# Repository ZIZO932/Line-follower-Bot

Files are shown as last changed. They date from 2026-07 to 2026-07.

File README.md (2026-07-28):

# Line Follower Bot

so this is my line follower robot, built it for competition and it actually won first place at TechnoXian. because of that im now representing Egypt at the world competition in Thailand which is insane to me

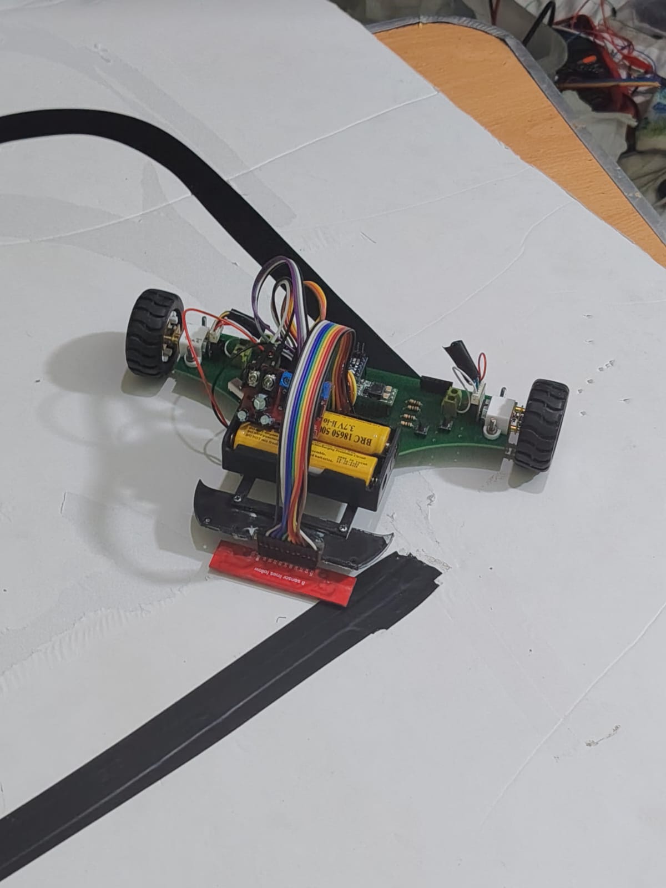
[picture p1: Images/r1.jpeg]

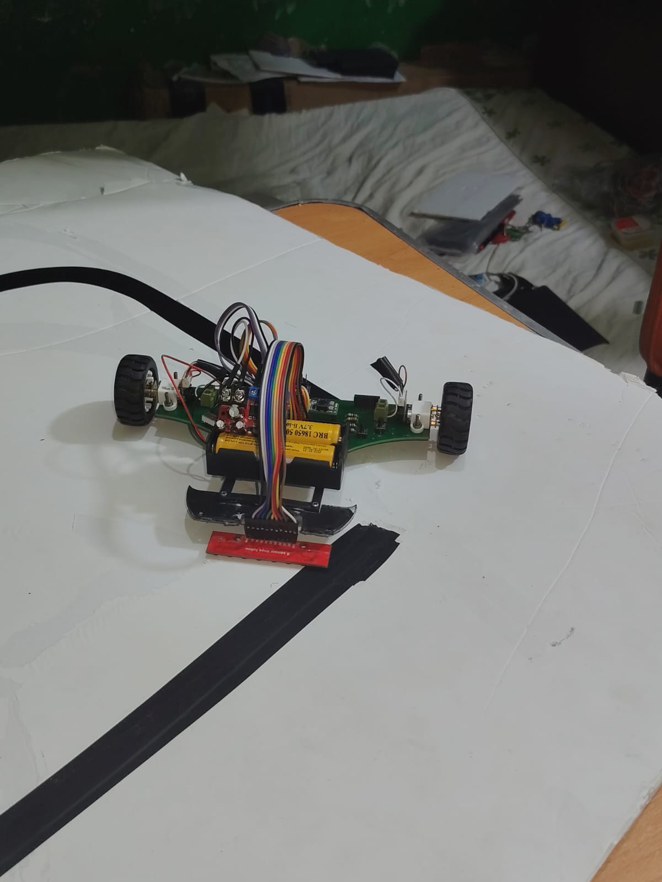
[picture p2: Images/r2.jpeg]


## what it is

a robot that follows a line using a sensor array under it and PID control to stay centered on the line. it can handle straights and sharp turns without losing the line. also has bluetooth so i can change the PID values live instead of reuploading code every single time i want to test something, which saved me so much time

## why i built it

wanted to actually understand PID instead of just copy pasting code from somewhere. looked at a bunch of existing line followers first, found one that used an Arduino Pro Mini with sensor calibration and liked that idea so i built my own version around it from scratch

## what's on it

- Arduino Pro Mini as the brain
- DRV8835 motor driver for the two motors
- QTR-8RC 8 channel line sensor array
- HC-05 bluetooth module for tuning
- 7.4V battery + voltage regulator to step it down to 5V
- power switch and some buttons

final PID values ended up being Kp=0.02, Ki=0, Kd=0.6 after a LOT of testing

## how i built it

started with research, watched tutorials on PID and read up on other line followers. then did the schematic, arduino + motor driver + sensor array + bluetooth + power stuff all wired together. had a bunch of errors at first, went through it connection by connection until it was clean

after that moved to PCB. had footprint issues, fixed those, then laid everything out and routed it. checked it like 3 times for unconnected nets and bad spacing before i was happy with it. added mounting holes so it screws into the body properly

did the 3D model around the PCB, made a spot for the sensor to sit low and aligned with the ground, and a little support to hold the battery so it doesnt move around while its driving

before the PCB even came in i breadboarded everything to test it. checked the arduino uploads fine, HC05 connects, both motors spin both directions on the driver, all 8 sensor channels give readings, regulator puts out a clean 5V. found some wiring mistakes doing this which was good bc caught them early

once the PCB arrived i soldered everything on, checked it over for bridges and bad orientation, used a multimeter to check power/ground before turning it on for the first time. then flashed the first test code to make sure everything talked to each other

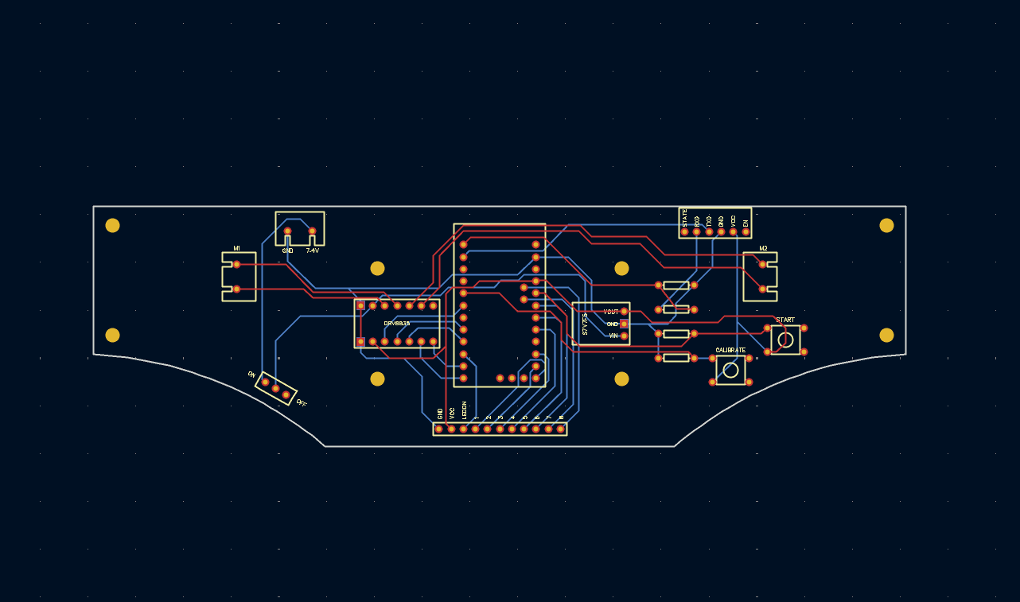
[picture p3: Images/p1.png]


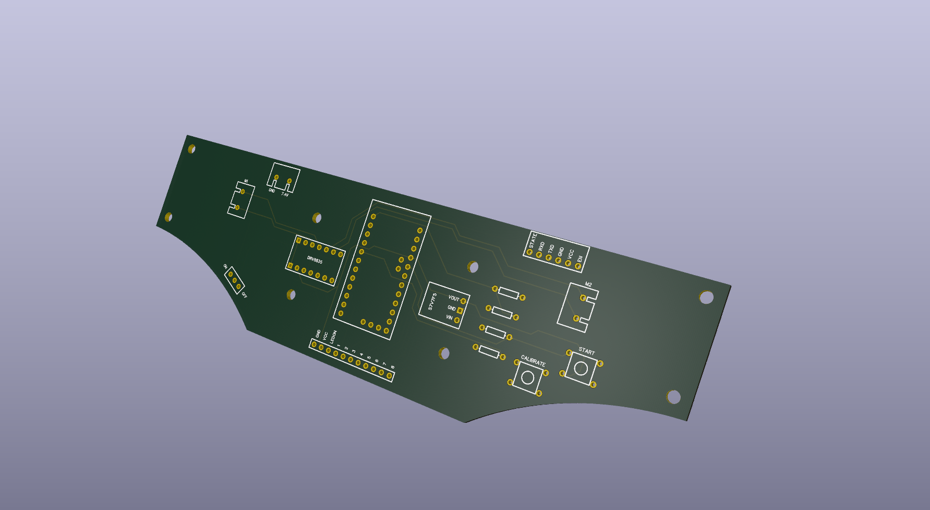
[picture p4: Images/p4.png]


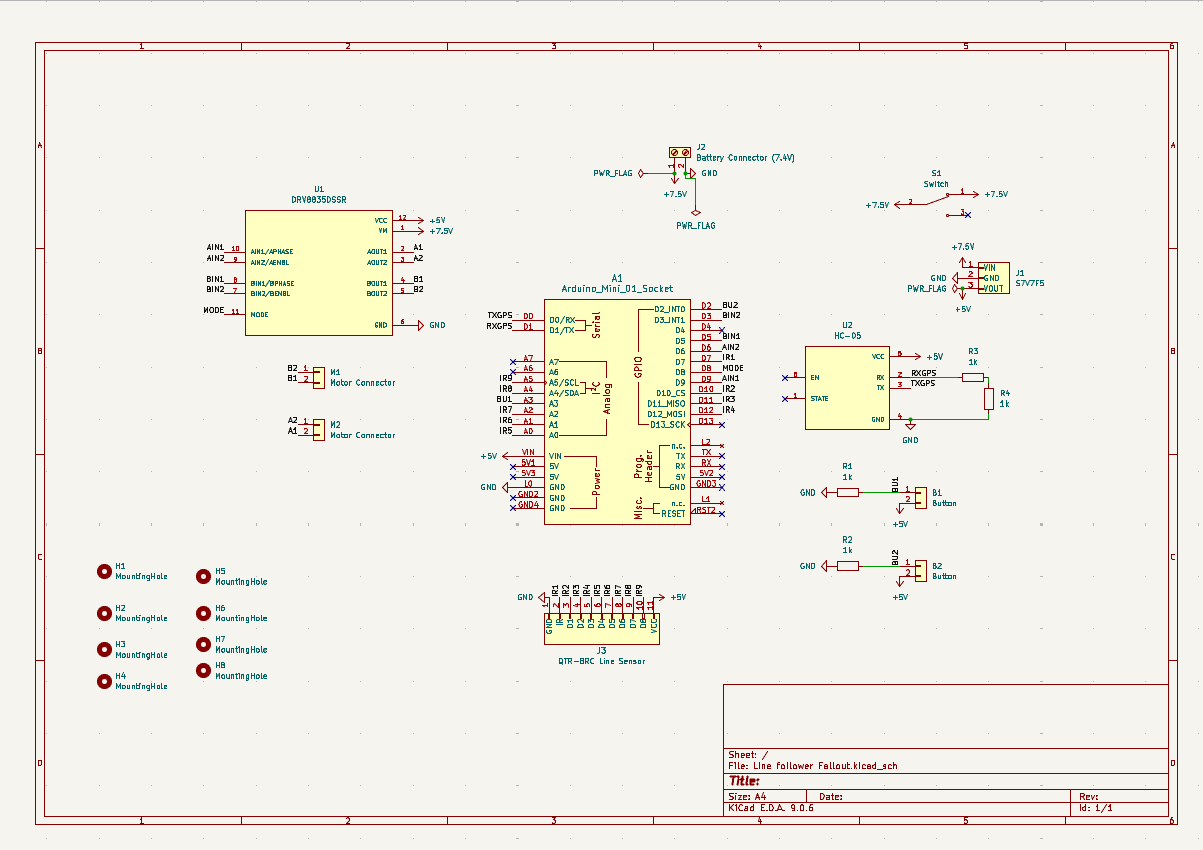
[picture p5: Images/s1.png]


## 3D model stuff

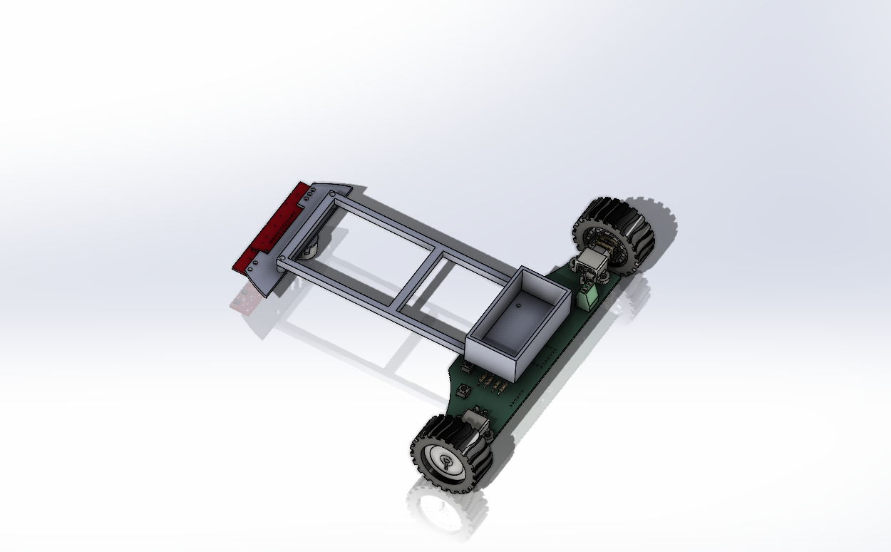
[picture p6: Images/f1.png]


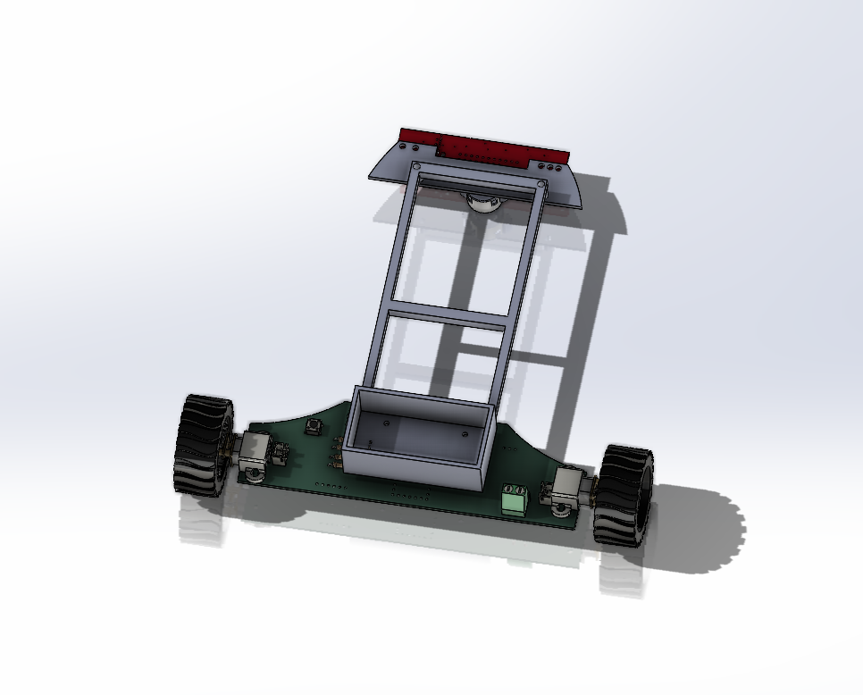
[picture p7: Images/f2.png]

## zine

made a zine for this project too, its in the repo

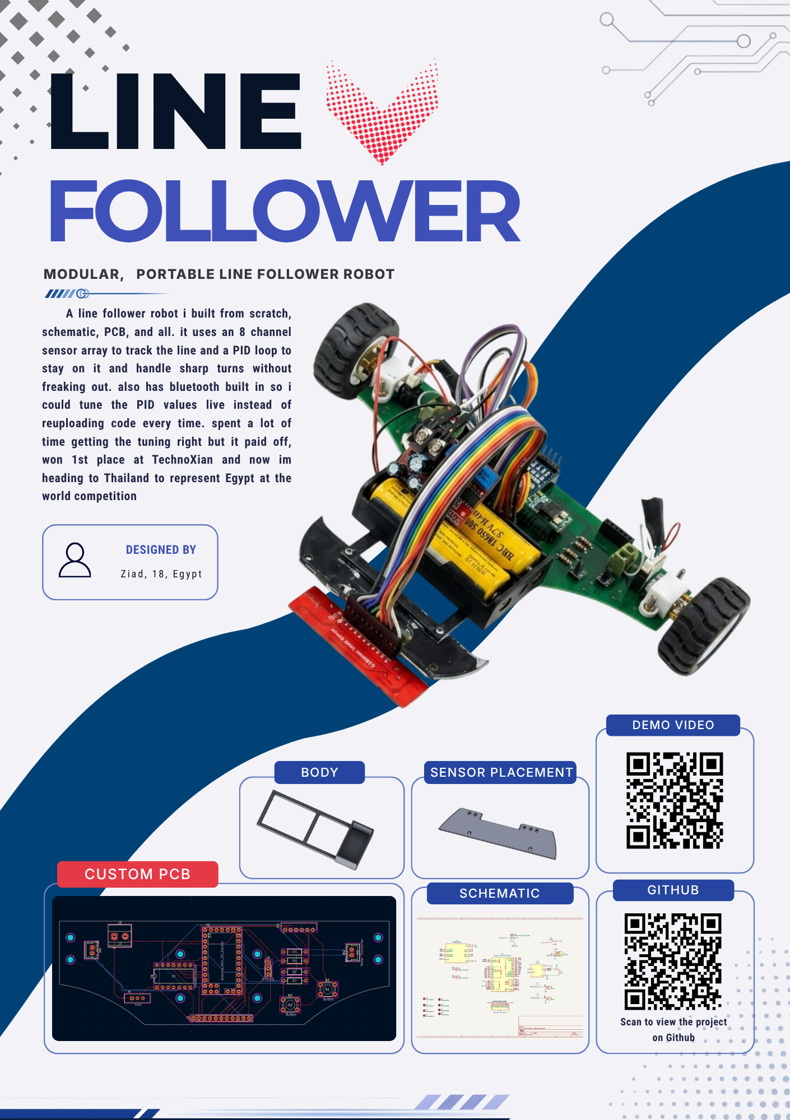
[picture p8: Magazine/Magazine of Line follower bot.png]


##BOM
|Component |Store |Qty|Unit Price (EGP)|Total (EGP) |Total (USD approx)|Link |
|---|---|---|---|---|---|---|
|Arduino Pro Mini 328 5V/16MHz |RAM Electronics |1  |250 |250 |4.98 |https://www.ram-e-shop.com/shop/arduino-mini-pro-arduino-pro-mini-328-5v-16mhz-7180 |
|DRV8835 Dual Motor Driver |Makers Electronics |1  |180 |180 |3.59 |https://makerselectronics.com/product/drv8833-2-channel-dc-motor-driver/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|
|QTR-8RC 8 Channel Line Sensor Array |Micro Ohm Electronics|1  |135 |135 |2.69 |https://microohm-eg.com/qtr-8rc-8-channel-line-tracker-reflectance-sensor-array/ |
|HC-05 Bluetooth Module (6 pin) |RAM Electronics |1  |200 |200 |3.98 |https://www.ram-e-shop.com/shop/kit-bluetooth-hc05-normal-hc-05-bluetooth-module-normal-6674 |
|7.4V Li-ion Battery Pack 2S-1P 1000mAh w/ BMS + JST|Makers Electronics |1  |210 |210 |4.18 |https://makerselectronics.com/product/rechargeable-li-ion-battery-pack-7-4v-2s-1pbms-1000mah-18650-with-jst-cable/ |
|L7805CV Voltage Regulator 5V/1A TO-220 |Micro Ohm Electronics|1  |6 |6 |0.12 |https://microohm-eg.com/product/7805-regulator-ic/ |
|DPDT Slide Power Switch (ON/ON 6 pin) |Micro Ohm Electronics|1  |10 |10 |0.2 |https://microohm-eg.com/on-on-switch-6-pin-pcb-mounted-22mm-dpdt-slide-switch/ |
|Tactile Push Button 12x12x12mm |Micro Ohm Electronics|1  |3.5 |3.5 |0.07 |https://microohm-eg.com/press-12x12x12mm-push-button-switch-4-pin/ |
|TOTAL | | | |994.50 (incl. DRV8835 estimate)|19.81 | |
## Demo videoo 

recorded a demo video that shows it can handle a small map in the s shape: https://youtu.be/TAyl4BceC5A

## results

first place at TechnoXian. now heading to the world competition in Thailand to represent Egypt

## made by

Ziad u can call me Zizo too if u want

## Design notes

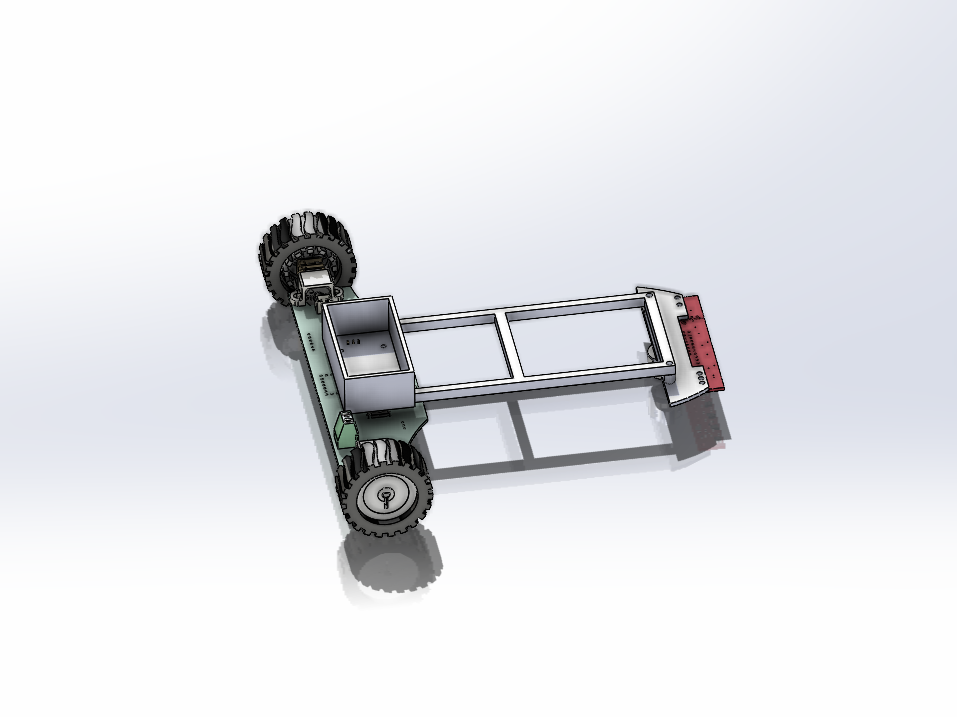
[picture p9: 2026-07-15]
Images/f3.png

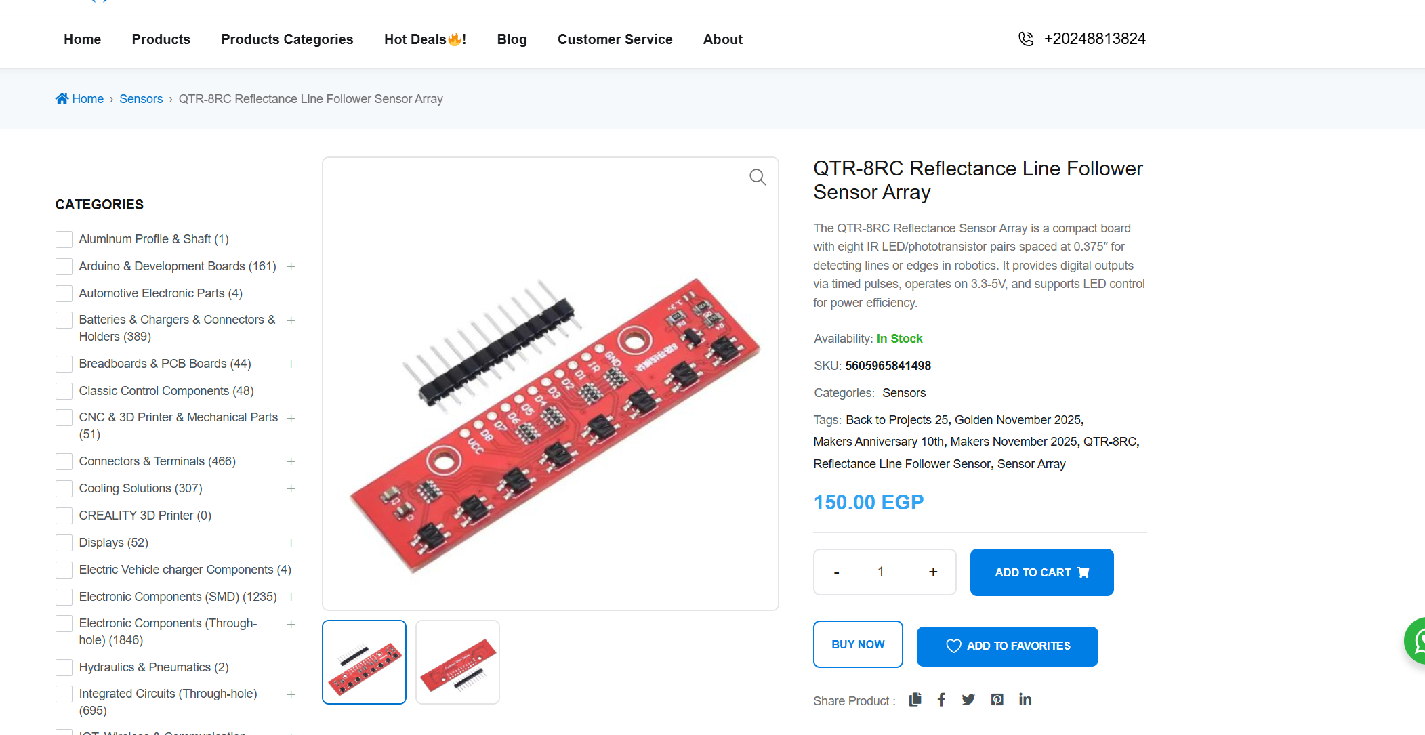
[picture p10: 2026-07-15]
Images/qtr.png

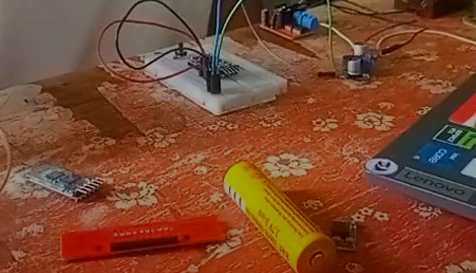
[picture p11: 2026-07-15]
Images/Screenshot 2026-07-15 085233 - Copy.png

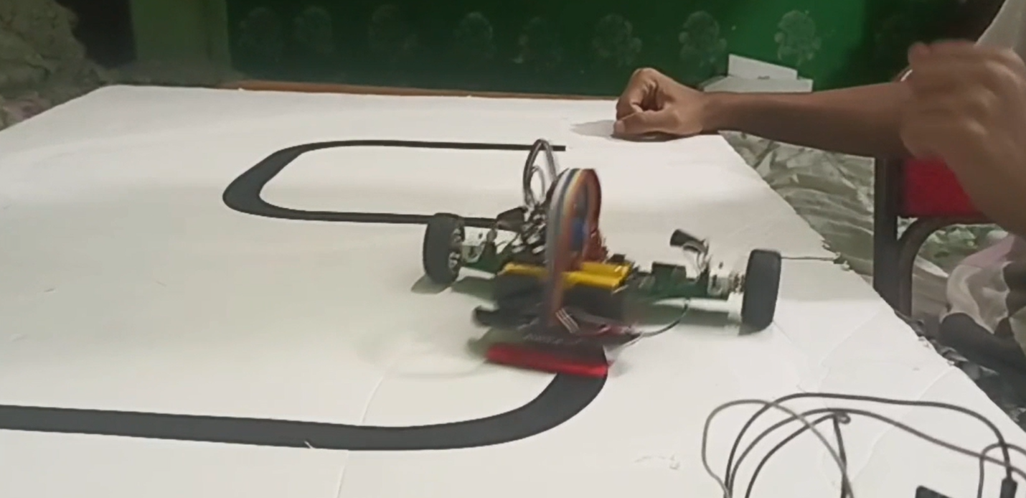
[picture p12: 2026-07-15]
Images/Screenshot 2026-07-15 090606 - Copy.png

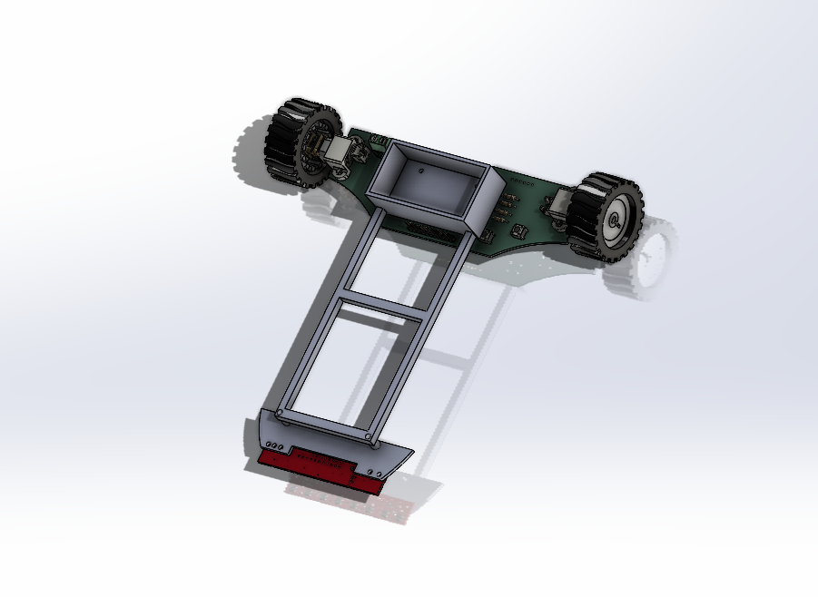
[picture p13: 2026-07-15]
Images/f5.png

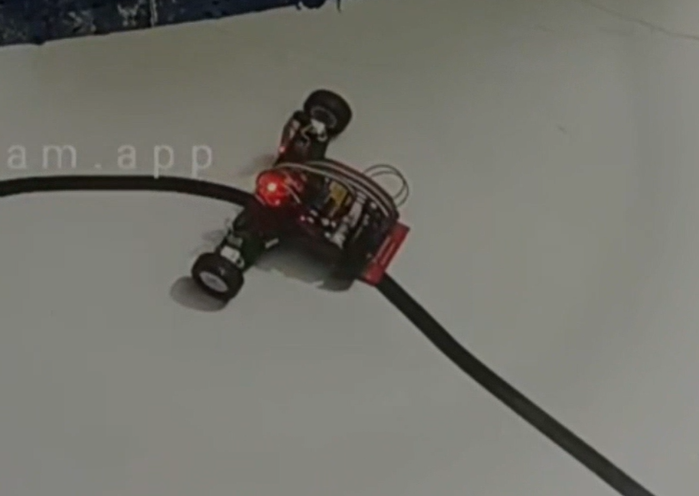
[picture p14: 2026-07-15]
Images/Screenshot 2026-07-15 090655 - Copy.png

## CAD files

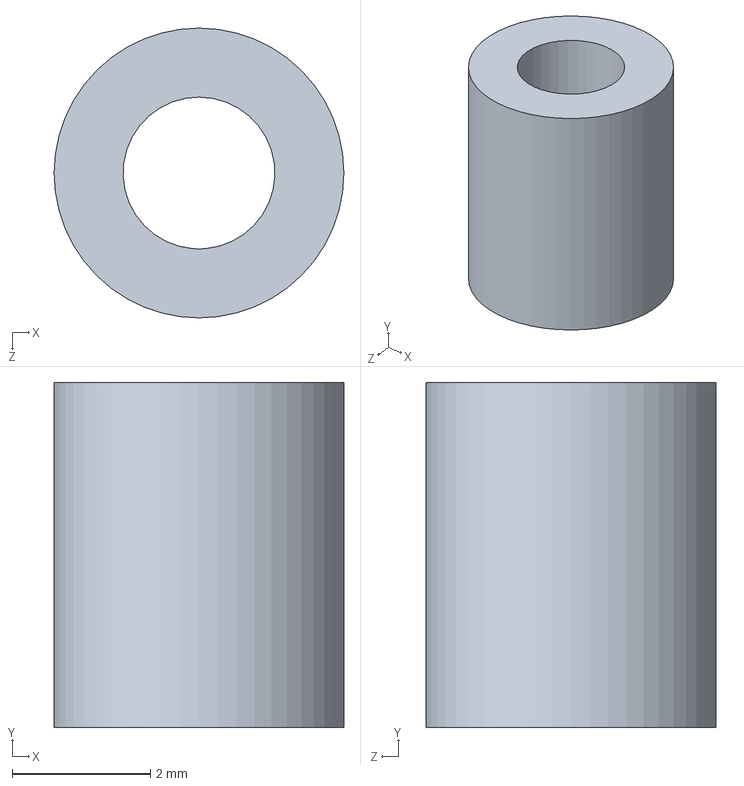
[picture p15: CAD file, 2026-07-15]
3D model source/Element1.SLDPRT
4.20 x 5.00 x 4.20 mm

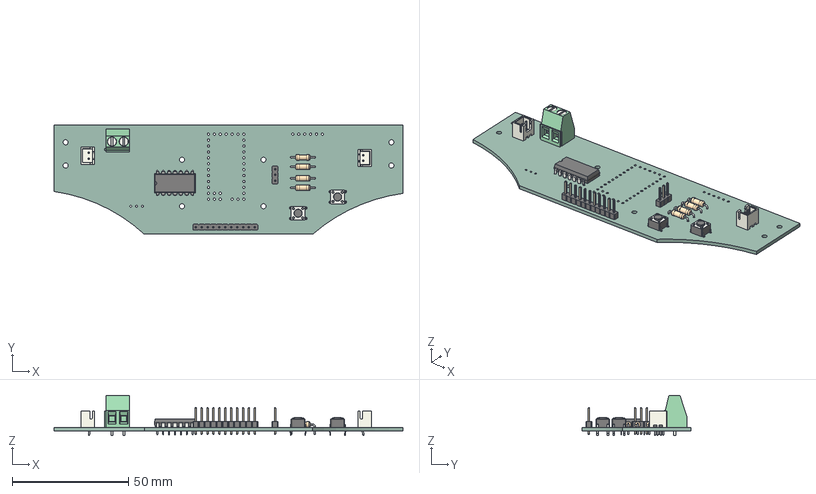
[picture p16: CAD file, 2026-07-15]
CAD/Line follower Fallout.step
150.0 x 47.0 x 17.3 mm
R_Axial_DIN0207_L6.3mm_D2.5mm_P10.16mm_Horizontal x 4
JST_XH_B2B-XH-A_1x02_P2.50mm_Vertical x 2
DIP-14_W10.16mm
TerminalBlock_Phoenix_MKDS-1,5-2-5.08_1x02_P5.08mm_Horizontal
PinHeader_1x03_P2.54mm_Vertical
SW_PUSH_6mm_H4.3mm x 2
PinHeader_1x11_P2.54mm_Vertical
Line follower Fallout_PCB

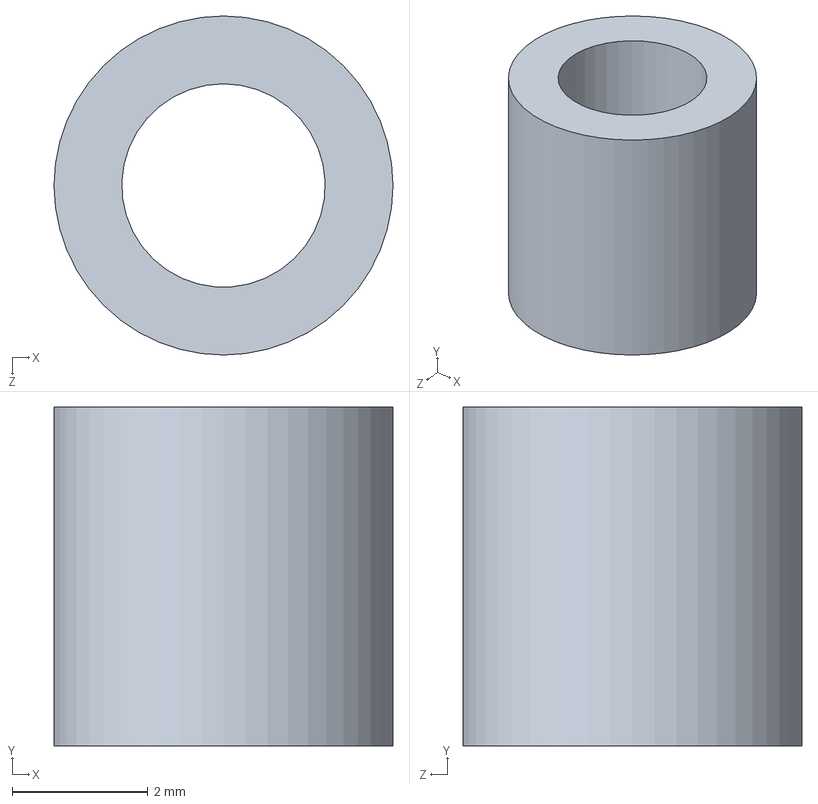
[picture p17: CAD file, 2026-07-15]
3D model source/Element2.SLDPRT
5.00 x 5.00 x 5.00 mm

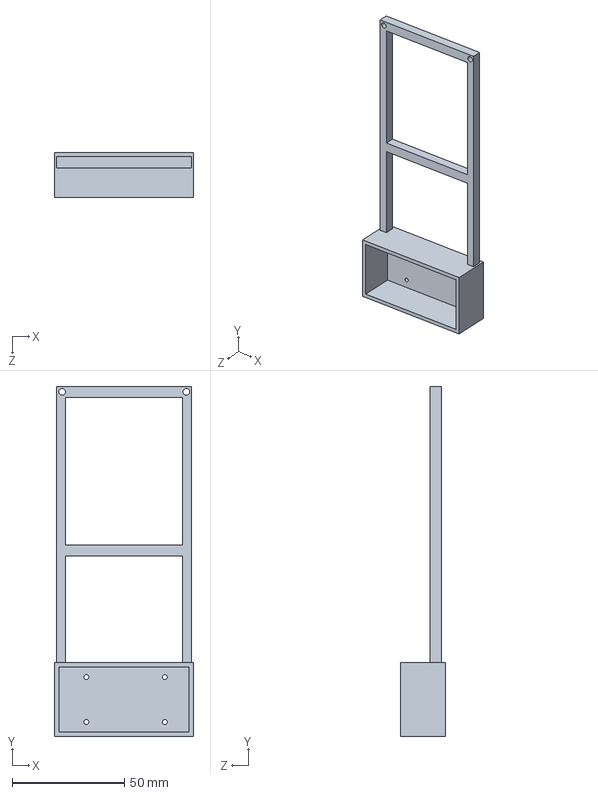
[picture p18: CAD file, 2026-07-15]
3D model source/battery support.SLDPRT
62.0 x 156.0 x 20.0 mm

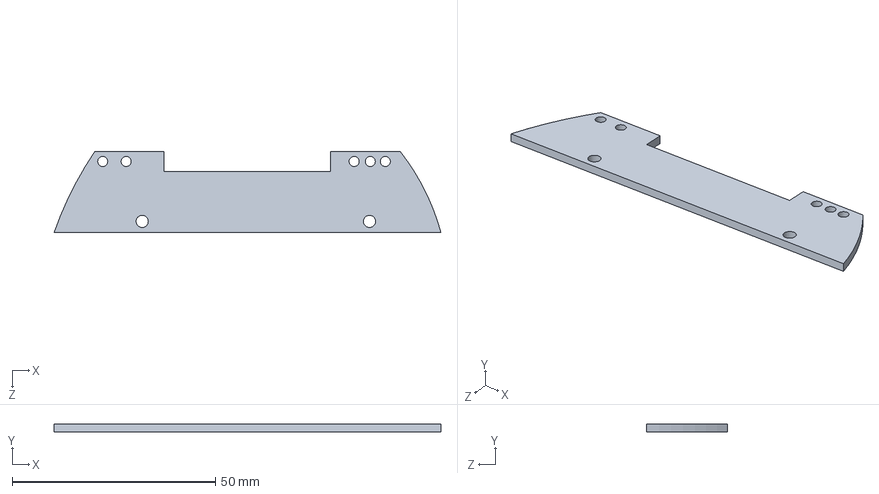
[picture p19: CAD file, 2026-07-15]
3D model source/Sensor placement.SLDPRT
95.1 x 2.00 x 20.0 mm

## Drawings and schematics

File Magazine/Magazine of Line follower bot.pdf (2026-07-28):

# LINE

# FOLLOWER

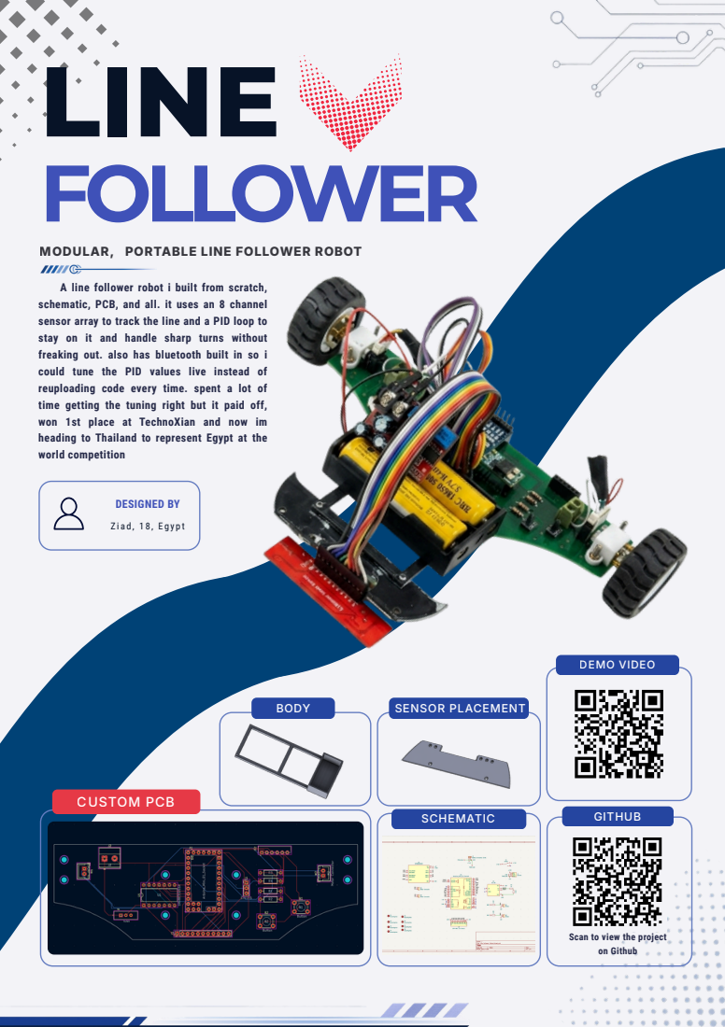
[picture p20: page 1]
A line follower robot i; built from scratch,; schematic, PCB, and all. it; uses; an 8 channel; freaking out. also has bluetooth; built in so i; won 1st place at TechnoXian; and now im; heading to Thailand to represent; Egypt at the; DEMO VIDEO; DESIGNED BY; SCHEMATIC; BODY; SENSOR PLACEMENT; CUSTOM PCB; GITHUB

MODULAR, PORTABLE LINE FOLLOWER ROBOT

sensor array to track the line and a PID loop to
stay on it and handle sharp turns without
could tune the PID values live instead of
reuploading code every time. spent a lot of
time getting the tuning right but it paid off,
world competition

Scan to view the project
on Github

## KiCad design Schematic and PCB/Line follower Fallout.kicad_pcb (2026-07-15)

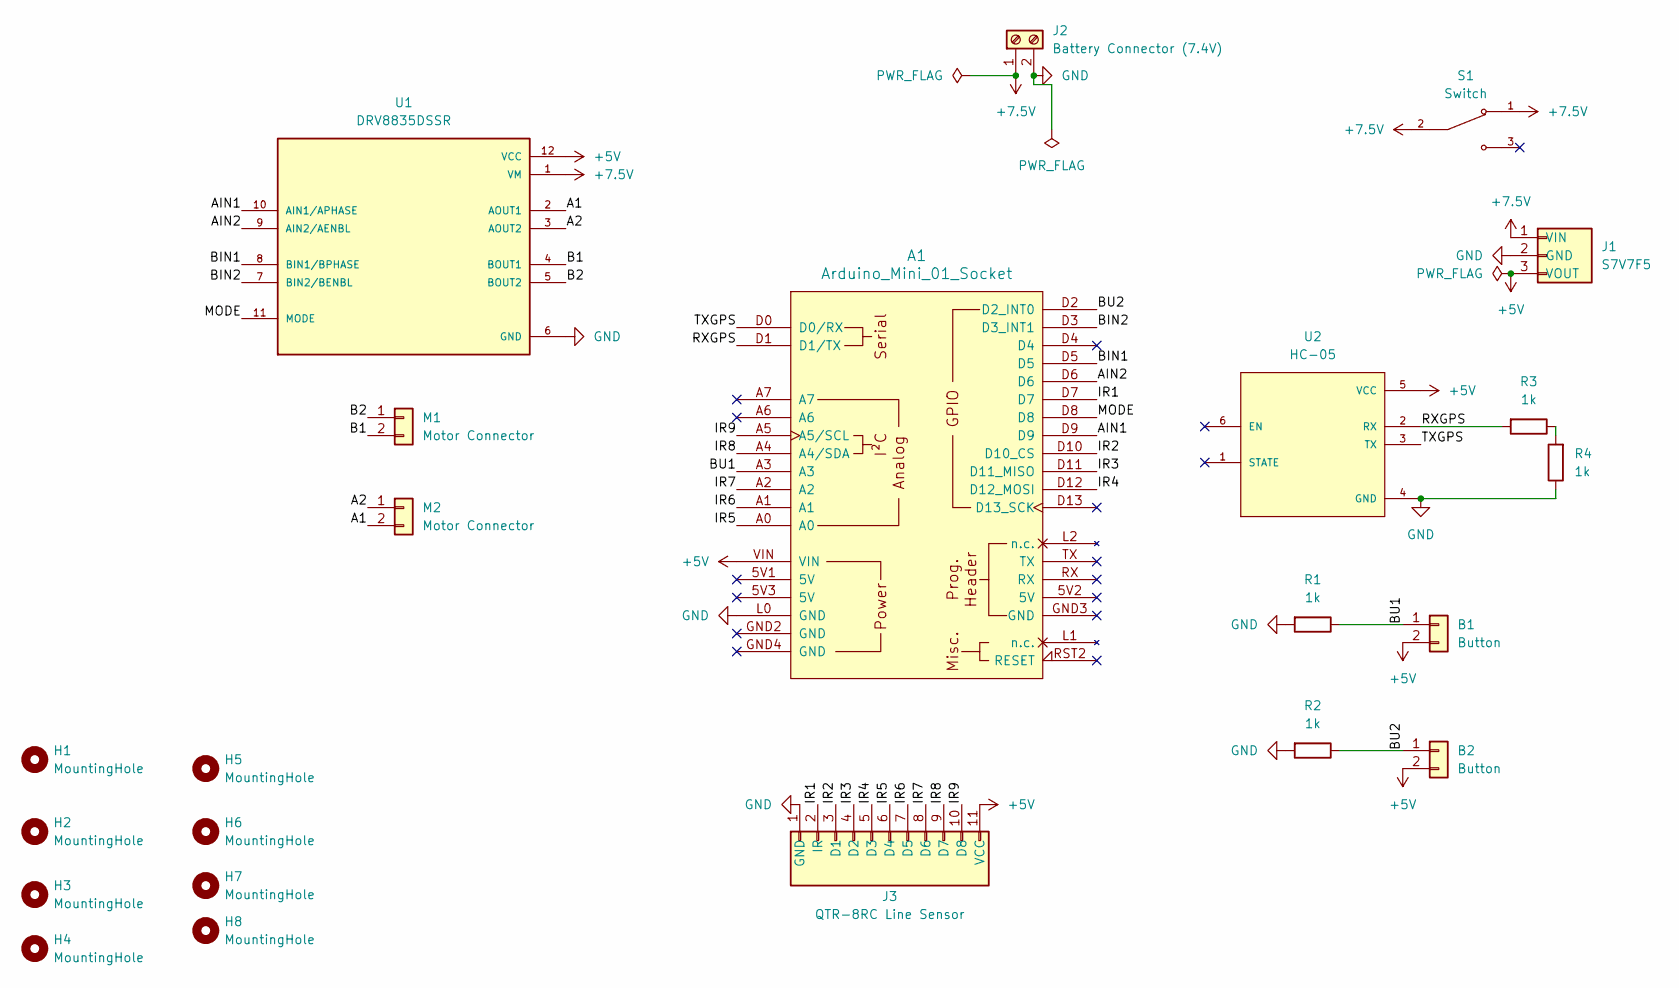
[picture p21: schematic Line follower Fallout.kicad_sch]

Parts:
A1: Arduino_Mini_01_Socket; Arduino_Mini_Socket
B1, B2: Button; SW_PUSH_6mm_H4.3mm
H1, H2, H3, H4, H5, H6, H7, H8: MountingHole; MountingHole_2.2mm_M2_DIN965
J1: S7V7F5; PinHeader_1x03_P2.54mm_Vertical
J2: Battery Connector (7.4V); TerminalBlock_Phoenix_MKDS-1,5-2-5.08_1x02_P5.08mm_Horizont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
J3: QTR-8RC Line Sensor; PinHeader_1x11_P2.54mm_Vertical
M1, M2: Motor Connector; JST_XH_B2B-XH-A_1x02_P2.50mm_Vertical
R1, R2, R3, R4: 1k; R_Axial_DIN0207_L6.3mm_D2.5mm_P10.16mm_Horizontal
S1: Switch; SW_MINI-SPDT-SW; PARTREV C
U1: DRV8835DSSR; DIP-14_W10.16mm; PARTREV H
U2: HC-05; MODULE_ZC142200; PARTREV N/A

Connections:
+5V: A1.VIN, B1.2, B2.2, J1.3 (VOUT), J3.11 (VCC), U1.12 (VCC), U2.5 (VCC)
+7.5V: J1.1 (VIN), J2.1, S1.1, S1.2, U1.1 (VM)
/A1: M2.2, U1.2 (AOUT1)
/A2: M2.1, U1.3 (AOUT2)
/AIN1: A1.D9, U1.10 (AIN1/APHASE)
/AIN2: A1.D6, U1.9 (AIN2/AENBL)
/B1: M1.2, U1.4 (BOUT1)
/B2: M1.1, U1.5 (BOUT2)
/BIN1: A1.D5, U1.8 (BIN1/BPHASE)
/BIN2: A1.D3 (D3_INT1), U1.7 (BIN2/BENBL)
/BU1: A1.A3, B1.1, R1.1
/BU2: A1.D2 (D2_INT0), B2.1, R2.1
/IR1: A1.D7, J3.2 (IR)
/IR2: A1.D10 (D10_CS), J3.3 (D1)
/IR3: A1.D11 (D11_MISO), J3.4 (D2)
/IR4: A1.D12 (D12_MOSI), J3.5 (D3)
/IR5: A1.A0, J3.6 (D4)
/IR6: A1.A1, J3.7 (D5)
/IR7: A1.A2, J3.8 (D6)
/IR8: A1.A4 (A4/SDA), J3.9 (D7)
/IR9: A1.A5 (A5/SCL), J3.10 (D8)
/MODE: A1.D8, U1.11 (MODE)
/RXGPS: A1.D1 (D1/TX), R3.2, U2.2 (RX)
/TXGPS: A1.D0 (D0/RX), U2.3 (TX)
GND: A1.L0 (GND), J1.2 (GND), J2.2, J3.1 (GND), R1.2, R2.2, R4.1, U1.6 (GND), U1.13 (GND), U2.4 (GND)
unnamed: R3.1, R4.2

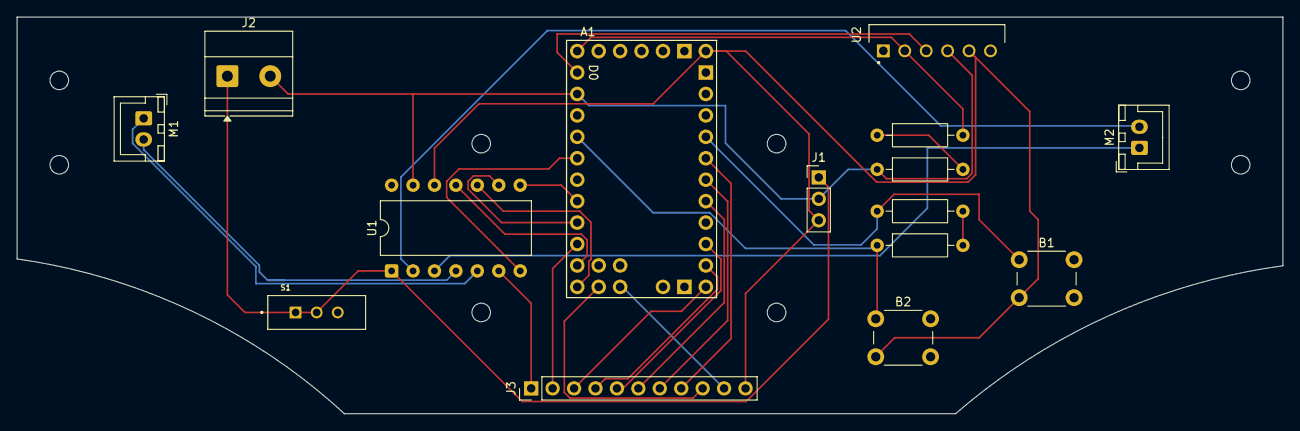
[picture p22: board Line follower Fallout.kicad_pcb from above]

Board: 2 copper layers, 150.0 x 47.0 mm, 23 parts (0 on the bottom side), 26 nets.

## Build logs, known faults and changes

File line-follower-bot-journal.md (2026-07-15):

# Line follower Bot — Journal Export

- Exported at: 2026-07-15T06:11:32Z
- Project ID: 4428
- Entries: 8

## Entry 1
- ID: 13294
- Author: Ziad
- Created At: 2026-06-11T19:24:27Z

### Content

I spent the first part of the session searching for line followers that were made before to understand different designs and features that people use I looked at several projects and compared their approaches

After that I watched a few tutorials about PID control because I wanted to understand how it is used in line followers and how it helps the robot stay on the line more accurately I took some notes about how the proportional integral and derivative terms affect the movement

While searching I found a line follower project that used an Arduino Pro Mini and had a calibration feature for the sensors I liked the idea because it makes the robot easier to tune and adapt to different surfaces so I decided to develop something similar and build on that concept

Once I had a clear idea of the direction I wanted to take I started working on the schematic I began selecting the main components and placing them in the design and started thinking about how everything would connect together

By the end of the session I had a better understanding of PID control found a reference design that inspired me and made a good start on the schematic for the project
Screenshot 2026-06-11 222310.png

### Recording Links

- https://lookout.hackclub.com/api/media/1ee6c6aa-5176-49f8-a314-ec5035d8cf9c/video.mp4
- https://lookout.hackclub.com/api/media/26d9dfbe-337a-4e05-9a73-93e6f61128a3/video.mp4

## Entry 2
- ID: 13342
- Author: Ziad
- Created At: 2026-06-12T01:35:30Z

### Content

Today I worked on building the full schematic for my line follower project and moving into the PCB stage

I started by placing and connecting all the components that I planned to use in the design I used an Arduino Pro Mini as the main controller and connected a DRV8835 motor driver to control the two motors I added the QTR 8RC line sensor array for line detection and also added an HC05 module so I can communicate with the robot wirelessly

For power I added a 7 4V battery connector a voltage regulator to step the voltage down to 5V and a switch to control powering the system on and off I also added the motor connectors buttons for interaction and all the needed power and ground connections

After connecting everything together I spent time checking the schematic because I started getting errors I went through the connections one by one fixed missing connections corrected labels and solved the schematic issues until everything was working correctly and no errors remained

After finishing the schematic I moved to the PCB stage and generated the board but I found footprint problems with some components so I stopped and checked each part and assigned the correct footprints where needed then updated everything until the errors were solved

Once the footprints were fixed I returned to the PCB editor and started making the basic board design I placed the main components and started arranging them in positions that made sense for routing and for keeping the design compact I also thought about where the sensors motors and power parts should be placed to make the final robot easier to build
Screenshot 2026-06-12 043354.png
Screenshot 2026-06-12 043515.png

### Recording Links

- https://lookout.hackclub.com/api/media/3d41e46e-c34e-4642-b2f9-95879c4b8c31/video.mp4

## Entry 3
- ID: 14589
- Author: Ziad
- Created At: 2026-06-16T18:13:27Z

### Content

Today I continued working on the line follower project and focused on completing the PCB design and making sure everything was ready for manufacturing

I started by returning to the PCB editor and continued arranging the components and routing the connections between them I adjusted the placement of the Arduino Pro Mini motor driver sensor module power components and connectors to make the layout cleaner and easier to assemble

After finishing the routing I spent time reviewing the entire PCB carefully I checked all electrical connections looked for unconnected nets verified that the traces were connected correctly and made sure the footprints matched the actual components that will be used in the build

I also checked spacing between components and made small adjustments to improve the overall layout and reduce possible issues during assembly I reviewed the power lines and signal routing again to make sure the design was organized and practical

Once everything was finished I ran final checks on the PCB and confirmed that no errors remained By the end of the session I completed the PCB design and verified that all parts and connections were correct so the project is now ready for the next stage
Screenshot 2026-06-16 210753.png

### Recording Links

- https://lookout.hackclub.com/api/media/ba944d98-a3b4-4ada-8503-a037b5b4fc95/video.mp4

## Entry 4
- ID: 16007
- Author: Ziad
- Created At: 2026-06-21T20:19:43Z

### Content

Today I continued working on the line follower project and focused on completing the PCB design and improving the 3D model for the robot structure

I started by finishing the PCB design and making the final mechanical adjustments I added mounting holes to the PCB so it can be fixed securely to the robot using screws and made sure the hole positions fit with the planned structure and component placement

After completing the PCB I moved to the 3D model and continued developing the mechanical design I finished positioning the line sensor in its intended location while considering alignment and accessibility for line detection

I also worked on designing and completing the battery support to hold the battery in place and improve stability during operation I checked the arrangement of the components to make sure everything fits together properly inside the final design

By the end of the session I completed the remaining PCB details and finished important parts of the 3D model including the sensor placement and battery support which moved the project closer to the assembly stage

Screenshot 2026-06-19 185559.png
Screenshot 2026-06-21 231712.png
Screenshot 2026-06-21 231729.png

### Recording Links

- https://lookout.hackclub.com/api/media/f1cb6cfb-ea6d-46ac-83e4-986573483a9f/video.mp4
- https://lookout.hackclub.com/api/media/10fad719-669b-4f6e-be91-77cb3ace35ad/video.mp4
- https://lookout.hackclub.com/api/media/7fdac8b6-58dd-4701-bfe3-7248eea1ba46/video.mp4

## Entry 5
- ID: 16607
- Author: Ziad
- Created At: 2026-07-14T17:01:00Z

### Content

so I finished the full 3D assembly for the project I went through all the parts one last time and made sure everything fit together correctly I checked the clearances the mounting points and the overall assembly to make sure it can actually be manufactured and assembled in real life without any problems

After finishing the assembly I reviewed the design again and made a few small adjustments to improve the final model After that I exported the files that I will need later for manufacturing

I also finished working on the zine and completed all the sections that I wanted to include Unfortunately I noticed afterwards that it was not being recorded so I could not log that work separately Because of that I will attach the finished zine to this journal as evidence even though I was not able to create a separate time log for it

Copy of Magazine Terraskipper (5.83 x 8.27 in).png
Screenshot 2026-06-25 141215.png
Screenshot 2026-06-25 141249.png

### Recording Links

- https://lookout.hackclub.com/api/media/99444daf-5253-4642-a4bd-067503189e8b/video.mp4

## Entry 6
- ID: 16618
- Author: Ziad
- Created At: 2026-07-15T05:53:16Z

### Content

 I focused on testing the hardware components before receiving the PCB I wanted to make sure that every part was working properly so I would not run into problems later during assembly

I started by checking the Arduino Pro Mini and made sure I could upload code to it without any issues After that I tested the HC05 Bluetooth module and confirmed that it could power on and communicate correctly

I also tested the DRV8835 motor driver with the DC motors to make sure both motors could run in both directions and respond correctly to different commands I checked the QTR 8RC line sensor array and verified that all of the sensors were giving readings and responding when detecting different surfaces

After that I checked the voltage regulator to make sure it was providing a stable 5V output from the battery input I also tested the push buttons battery connector switch and motor connectors to make sure they were all working as expected

During the session I found a few small wiring mistakes while testing on a breadboard and fixed them before testing again I repeated several tests to make sure the results were consistent and that all the components were ready to be soldered once the PCB arrived
Screenshot 2026-07-15 085233.png

### Recording Links

- https://lookout.hackclub.com/api/media/25004379-5667-42bb-8d1e-cebe58dadb36/video.mp4

## Entry 7
- ID: 16619
- Author: Ziad
- Created At: 2026-07-15T06:01:04Z

### Content

I finally received the PCB and started assembling the robot

I began by soldering all the components onto the PCB I mounted the Arduino Pro Mini the DRV8835 motor driver the HC05 Bluetooth module the voltage regulator the motor connectors the sensor connector the buttons the power switch and the battery connector I took my time while soldering to make sure every joint was clean and secure

After everything was mounted I carefully inspected the whole board I checked the orientation of every component looked for solder bridges and made sure there were no missing connections I also used a multimeter to check the power and ground lines and verified that there were no shorts before powering the board

Once I was confident that everything was assembled correctly I powered the board for the first time and confirmed that the power system was working as expected I also checked that the main components were receiving the correct voltage

After confirming that the hardware was working I started programming the robot I uploaded the first test programs to make sure the Arduino was communicating with the different components correctly I tested the motors the Bluetooth module and the line sensor and made small changes to the code whenever I found something that needed to be adjusted




### Recording Links

- https://lookout.hackclub.com/api/media/d4ccbbfd-59cf-4794-949d-e7742fffb375/video.mp4
- https://lookout.hackclub.com/api/media/55a7da6d-a39f-4aa8-835e-d6e05643143c/video.mp4
- https://lookout.hackclub.com/api/media/fe397bda-dc3d-4684-b71f-3ebde869d077/video.mp4
- https://lookout.hackclub.com/api/media/629652fc-53cf-4089-b89f-3d9a751c8d45/video.mp4

## Entry 8
- ID: 16620
- Author: Ziad
- Created At: 2026-07-15T06:08:11Z

### Content

I spent the whole session improving the software for the line follower and testing how it performed

I made a simple test track to use while tuning the robot and started running it over and over again Every time I noticed a problem I stopped changed the code uploaded it again and tested it one more time

Most of the time was spent adjusting the PID values I changed the proportional integral and derivative values little by little to see how each one affected the robot Sometimes the robot reacted too aggressively and sometimes it was too slow so I kept making small changes until the movement became much smoother

I also experimented with different motor speed values I tested higher and lower speeds and checked how they affected the robot while driving through straight sections and sharp turns I wanted to find a balance between speed and stability without causing the robot to lose the line

Throughout the session I repeated this process many times I modified the code uploaded it tested the robot watched how it behaved took notes and made another round of changes I also adjusted a few other parts of the program to improve the overall performance and make the robot respond more consistently
Screenshot 2026-07-15 090655.png
Screenshot 2026-07-15 090639.png
Screenshot 2026-07-15 090606.png

### Recording Links

- https://lookout.hackclub.com/api/media/73483484-4930-4003-b7ce-c868ede543f3/video.mp4
- https://lookout.hackclub.com/api/media/f4cc3b57-285a-4b20-bc28-07faad617c9b/video.mp4
- https://lookout.hackclub.com/api/media/7cdc500a-6e82-4107-9eed-db21b3c7509d/video.mp4
- https://lookout.hackclub.com/api/media/196ba071-f328-4cc7-9da2-fd046845c00c/video.mp4
- https://lookout.hackclub.com/api/media/aef4c62e-057a-4786-b8d6-0f16acbe99f3/video.mp4

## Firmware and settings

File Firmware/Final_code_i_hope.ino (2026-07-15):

int ain1 = 9;
int ain2 = 6;
int bin1 = 5;
int bin2 = 3;

void setup() {
  pinMode(ain1, OUTPUT);
  pinMode(ain2, OUTPUT);
  pinMode(bin1, OUTPUT);
  pinMode(bin2, OUTPUT);
}

void loop() {
  // Test 1: Motor A forward
  analogWrite(ain1, 150);
  digitalWrite(ain2, LOW);
  digitalWrite(bin1, LOW);
  digitalWrite(bin2, LOW);
  delay(2000);

  // Stop
  digitalWrite(ain1, LOW);
  digitalWrite(ain2, LOW);
  digitalWrite(bin1, LOW);
  digitalWrite(bin2, LOW);
  delay(1000);

  // Test 2: Motor A backward
  digitalWrite(ain1, LOW);
  analogWrite(ain2, 150);
  digitalWrite(bin1, LOW);
  digitalWrite(bin2, LOW);
  delay(2000);

  // Stop
  digitalWrite(ain1, LOW);
  digitalWrite(ain2, LOW);
  digitalWrite(bin1, LOW);
  digitalWrite(bin2, LOW);
  delay(1000);

  // Test 3: Motor B forward
  digitalWrite(ain1, LOW);
  digitalWrite(ain2, LOW);
  analogWrite(bin1, 150);
  digitalWrite(bin2, LOW);
  delay(2000);

  // Stop
  digitalWrite(ain1, LOW);
  digitalWrite(ain2, LOW);
  digitalWrite(bin1, LOW);
  digitalWrite(bin2, LOW);
  delay(1000);

  // Test 4: Motor B backward
  digitalWrite(ain1, LOW);
  digitalWrite(ain2, LOW);
  digitalWrite(bin1, LOW);
  analogWrite(bin2, 150);
  delay(2000);

  // Stop
  digitalWrite(ain1, LOW);
  digitalWrite(ain2, LOW);
  digitalWrite(bin1, LOW);
  digitalWrite(bin2, LOW);
  delay(1000);
}
